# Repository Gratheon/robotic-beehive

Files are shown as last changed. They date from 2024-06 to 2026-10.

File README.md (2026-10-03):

### gratheon/robotic-beehive
[Gratheon Robotic beehive](https://gratheon.com/products/robotic_beehive/) is a project to build a robotic beehive that inspects the colony without harming it.

#### Robotic Beehive (concept v3)
A weatherproof cabinet around a standard vertical hive. To inspect a box, the robot:
1. peels the stack above it apart one edge at a time and lifts it 400 mm;
2. lifts each frame straight up until its comb centre is level with two cameras (one per face), photographs both faces straight on, then sets it down in the free gap beside it, like a beekeeper working through a box;
3. closes the hive with a rolling landing so bees are pushed aside, not crushed.

The stack can mix deep brood boxes and shallow honey supers.

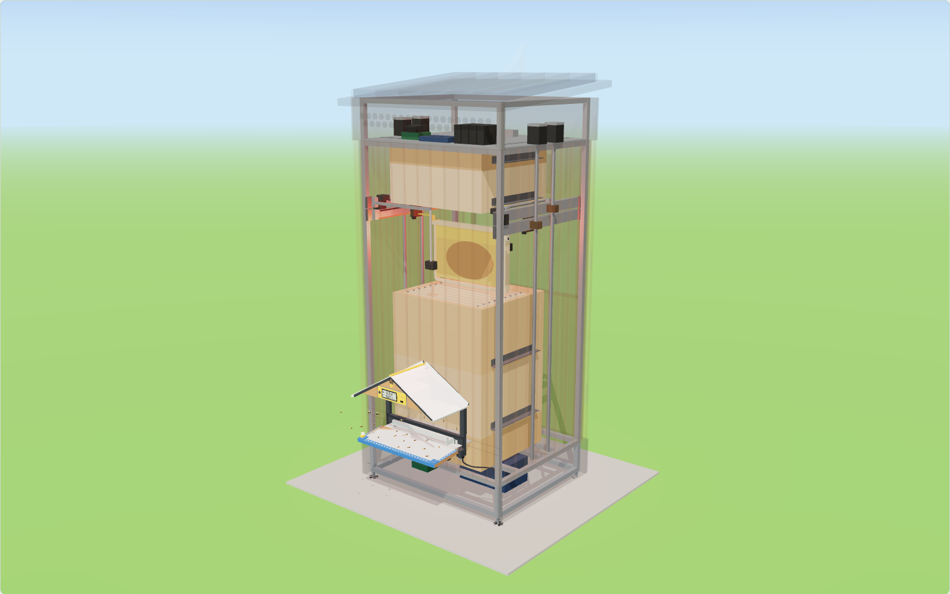
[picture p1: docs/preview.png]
Robotic Beehive 3D model: a frame lifted to the photo spot between the cameras (https://gratheon.com/products/robotic_beehive/)


**Live 3D preview:** [gratheon.com/products/robotic_beehive](https://gratheon.com/products/robotic_beehive/), or open `model/index.html` from this repo.

- **Design, bee welfare, weather, BOM, mobile roadmap:** [docs/DESIGN.md](docs/DESIGN.md)
- **Wiring:** [docs/WIRING.md](docs/WIRING.md)
- **3D model:** `model/index.html` (interactive, animated, opens from disk) and `model/hive-tower.glb` (the `inspection` animation clip is baked in)
- **Control code:** `hivebot/` (Python), plus a Klipper config in `firmware/klipper/hivebot.cfg`

#### View the model
Open `model/index.html` directly in a browser. It is a single self-contained file (three.js is bundled in) and works offline. Point at any part to see what it is and why it is there.

The model lives in `model/hive-model.js` (geometry and animation). The viewer is `viewer.js`, `viewer.html` and `viewer.css`. After a change, rebuild:
```bash
cd model && npm install   # first time only
npm run build             # regenerates index.html and hive-tower.glb
npm run website           # also updates the embed on gratheon.com (../../gratheon.com)
```

#### Run the controller
```bash
python3 -m pytest                    # sequences + bee-safety rules on the simulator
python3 -m hivebot plan --box 1      # dry run: every move, weights, visit time
python3 -m hivebot inspect --box 1   # real robot (Klipper + Moonraker on the Jetson)
python3 -m hivebot bench-move lift_left 700   # bench rig: DM542 on Jetson GPIO
```
The simulator refuses anything a careful beekeeper would refuse, such as landing the stack too fast or lifting a frame into bees hanging under the raised boxes. A code change that makes the robot rougher fails the tests.

#### Components
- NVIDIA Jetson Orin Nano: inspection, cameras, AI models, Klipper host
- BTT Octopus motion board running Klipper firmware
- 4 × NEMA23 on TR16×4 lead screws with DM542 drivers (2 lift beams, 2 scan beams)
- 2 × NEMA17 belt shuttles, 4 servos (forks, hooks)
- 2 × 12 MP frame cameras (one per face, straight on), 2 rim cameras, varroa sump camera
- ESP32 + LoRa always-on supervisor with load cells and climate sensors
- [Entrance Observer](https://github.com/Gratheon/entrance-observer) on the cabinet front (its own compute, PoE+ powered)
- 24 V power supply, optional solar + LiFePO4
- 22 mm aluminium extrusion skeleton

`main.py` is the original keyboard jog for a single DM542 on Jetson GPIO. The FreeCAD models of earlier concepts were removed in favour of `model/`; they remain in git history.

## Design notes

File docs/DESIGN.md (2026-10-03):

# Robotic Beehive: design (concept v3)

A static, weatherproof cabinet around a standard vertical hive. The robot inspects one box at a time:

1. It raises everything above that box by 400 mm, cracking the propolis seal one edge at a time.
2. It lifts each frame straight up, carries it to a photo spot in the middle of the box where two cameras, one per face, shoot both faces straight on, then sets it down in the free gap next to it.
3. It closes the hive again so that contact rolls across the rim.

Everything moving lives outside the bee space. The only changes to the hive itself are steel cleats on the boxes and two steel pins per frame.

- **3D model:** `model/index.html` (interactive, animated) and `model/hive-tower.glb` (with the `inspection` animation clip)
- **Wiring:** [WIRING.md](WIRING.md) and [wiring.svg](wiring.svg)
- **Control code:** `hivebot/` (Python) and `firmware/klipper/hivebot.cfg`

## 1. Why this layout

The hard problem is moving frames without killing bees. Frames are glued with propolis, the queen can be on any frame, and brood chills if it stays open too long. Three decisions follow from that:

| Decision | Why |
|---|---|
| **Lift frames straight up, never out sideways** | Bees that fall off a frame drop straight back into their own box, not onto the ground. The frame never tilts: warm, heavy comb breaks when it is not vertical. |
| **Split the stack instead of reaching in from the side** | Works with standard boxes. Side-opening boxes need custom joinery, and bees propolise every door shut. |
| **Put the hive in a cabinet** | Rain, wind and sun stay out. The air around an open box can be pre-warmed to 25 °C, so inspections are safe on 10–15 °C days. Disturbed bees stay inside instead of bothering neighbours, which matters for urban and corporate hives. The mechanics stay clean, and it can look like furniture instead of a pile of boxes. |

Two further choices do most of the bee-safety work:

- **Independent left/right lift beams.** Raising one edge 6 mm while the other stays down acts like a hive tool. It cracks the propolis seal with a fraction of the force a straight pull needs. Closing in the reverse order (left edge lands first, then right) makes the contact line roll across the rim and push bees aside.
- **The working gap.** Each box runs with one frame's worth of free space: 10 frames at 37.5 mm pitch leave a 25 mm gap. The robot works like a beekeeper:
  1. It pushes the frame next to the gap 10 mm into the gap, which breaks burr comb before lifting.
  2. It lifts the frame and photographs it.
  3. It sets the frame down in the gap. The gap has now moved one frame along.
  
  Lifting a frame straight up out of a full box would roll bees between the combs. That is how queens get killed.

## 2. Mechanism

Coordinates follow the model: X left/right, Y up, Z front (+, entrance) / back (−).

| Part | Specification |
|---|---|
| Skeleton | 4 corner posts of 22 mm aluminium extrusion, plinth ring, crown ring. Footprint 810 × 666 mm, height ≈1.88 m for two deep boxes and a super (≈1.99 m for three deep boxes; each extra box adds its own height). |
| Linear guides | MGN12 rail on the inner face of each post. Each post carries one lift-beam carriage and one scan-beam carriage. V-wheels on V-slot extrusion also work if the extrusion allows it. |
| Lift beams (L, R) | NEMA23 + DM542 + TR16×4 lead screw hung from the crown (the screw works in tension). A servo-turned fork shaft carries two fingers that swing under the box cleats. Bar load cells sit in the fork bearing blocks. |
| Scan beams (L, R) | Same drive as the lift beams. Each carries a belt-driven **shuttle** (NEMA17 + GT2) holding the frame hook and an inductive pin sensor. The scan beams lift each frame until its comb centre is level with the cameras. |
| Frame cameras | 2 × 12 MP (IMX477 class, 3.6 mm low-distortion M12 lens, about 83° × 67°), one per face, straight into the Orin Nano's two CSI ports. They hang from the **lift beams** (left beam: front camera, right beam: back camera), 265 mm in front of and behind the photo spot, between box and cladding, so they never pass over the hive. A ring strobe with crossed polarisers removes glare from nectar and capping. See *Cameras on the lift beams* and *Seeing into the cells* below. |
| Hook | A servo swings an L-shaped hook over the box wall. Its H-shaped tip plate has two back-to-back slots, so it can push a frame toward the gap in either direction. It slides sideways around the pin neck and never presses down on the top bars. Once the frame hangs, the pin head drops into a 1.5 mm pocket, so a lifted frame can be carried either way without sliding out. |
| Stack | Any mix of deep boxes (285 mm, 279 mm frames) for the brood nest and shallow supers (170 mm, 164 mm frames) for honey, set once per hive. The default is two deep boxes and one super. Cleats, pins and the 400 mm opening are the same for every box; the robot only needs each box's height. |
| Box changes | Stainless 30×30 angle cleat on the left and right walls of every box and the lid, 25 mm above the box bottom. They double as hand grips. |
| Frame changes | Two stainless M5 shoulder screws on each top bar ear (neck 2.5 mm, head 2.5 mm; they fit inside the bee space) and an ArUco tag on the end bar. |
| Bottom board | 150 mm tall screened "varroa sump": white tray, fixed wide-angle camera, no moving parts. |

**Cameras on the lift beams.** While a box is open the lift beams stand still at rim + 425 mm (cleat 25 mm + gap 400 mm), whatever the box. Cameras hung 265 mm below them therefore always sit 160 mm above the open rim, and the scan beam, now free of cameras, lifts each frame until its comb centre is level with them: 301.5 mm for a deep frame, 244 mm for a super frame. On the scan beam the cameras sat a fixed distance under the hook, which only centred one frame size.

The camera height has limits. For a deep frame it must be 150–165 mm above the rim, so the frame clears the rim and the scan beam stays 119 mm under the lift beam. So deep frames are centred with almost no room to move them up or down, while super frames have over 100 mm, enough to take two or three shots at different heights. A larger gap would give deep frames the same freedom, at the cost of a taller cabinet.

**Seeing into the cells.** A cell is 5.4 mm wide and about 11 mm deep, and it slopes up 9–13°. Eggs lie at the bottom, so to see an egg the camera must look within about 26° of the cell axis. Every frame is carried to the same photo spot, so distance, focus and mm-per-pixel are identical for every frame, and counts and cell sizes are comparable over time.

How many cameras is a cost/benefit question:

| Option | Cost | What it sees | Verdict |
|---|---|---|---|
| 1 camera, frame turned around | +1 camera, but a rotary axis on the hook carrying a 4 kg frame | Both faces, perfectly centred | Rotating a heavy, bee-covered frame inside the gap is a new failure mode (swinging comb, collisions). Not worth one camera. |
| **2 cameras, one per face (chosen)** | ≈€160, plug straight into the Orin Nano's two CSI ports | Whole face from 240 mm at about 9.5 px/mm (a cell ≈50 px, an egg ≈14 px). Centre of the comb within ~26°: eggs visible. Corners up to ~46°: larvae, capping, pollen and honey visible, eggs at the very bottom of a cell not. | Best balance. The brood nest, where eggs are, is usually the middle of the comb. |
| 4 cameras, two per face | ≈€320 plus a USB hub or CSI multiplexer | Worst corner ~35°, most of the comb within 25° | More cameras, cables and calibration for the comb corners, where eggs are rare. Only if the bench test shows corner eggs matter. |

Depth of field is not a reason for more cameras: comb is flat within about ±15 mm, and at 240 mm with the lens stopped to f/4–5.6 all of it is sharp.

Infrared is an open research question. The detection models Gratheon runs today (bees, queen, cells, varroa) are trained on visible-light photos, and cheap NoIR camera variants exist if a test shows infrared helps with mites or with seeing through the bees. Until then the cameras stay visible-light, with the white strobe.

**Bench test before buying hardware:** photograph a few real brood frames at 240 mm with one camera, centred and 45° off-axis, and count eggs found by eye and by the cell model. That decides between 2 and 4 cameras, and whether infrared is worth a second look.

- *Before (v3.0).* Cameras hung beside the frame's ends and looked along the face; the far half of the comb was seen up to 77° off-axis.
- *Low mount.* The cameras sit 10 mm below comb centre. Lower rows, whose cells slope away from the camera, are then seen more nearly along their axis.
- *Entrance.* The entrance is the [Entrance Observer](https://github.com/Gratheon/entrance-observer) porch, which runs through the cabinet front to the 300 mm slot. The scan beams never go below 535 mm, so the front camera always passes above it.
- *Short bee tunnel.* The hive stands 45 mm toward the cabinet front and the photo spot is 29 mm forward of the cabinet centre. The front camera still clears the hive by 10 mm, and the walk from the landing board to the hive entrance is about 70 mm instead of 115 mm.

**Why TR16×4 lead screws everywhere.** Each screw hangs from a thrust bearing in the crown, so the load puts it in tension and it cannot buckle.

- *Self-locking.* The lead angle is about 4.5°, so the stack or a frame stays put on power loss. No brakes needed.
- *Speed.* At 1.5 m length the whip limit is about 1000 rpm, which allows 40 mm/s frame lifts. The first choice, TR10×2, would have needed 1500 rpm, above its whip limit.
- *Torque.* Lifting 80 kg of honey supers needs ≈0.8 N·m per side, within a NEMA23's range at 24 V.

**Load limits.** The software stops a lift above 45 kg per side (90 kg of boxes above the target) and a peel above 60 kg. Heavy honey supers should be harvested before the stack outgrows that.

## 3. Inspection sequence

This is the sequence in `hivebot/sequences.py`. The simulator in `hivebot/motion/sim.py` enforces every rule in brackets.

1. **Pre-flight check** (`safety.evaluate`):
   - Outside ≥15 °C, or ≥10 °C with the cabinet pre-warmed to 25 °C.
   - No rain, wind below 8 m/s, between 10:00 and 16:00 (foragers are out).
   - At least 7 days since the last visit, battery OK, door closed, E-stop released.
2. Red work light on. Bees barely see light above ~620 nm.
3. The lift beams move to 8 mm below the cleats of the box above the target box. The forks swing in. *(A fork may only rotate at that height.)*
4. **Peel.** The left edge rises 6 mm at 1 mm/s, then the right edge. The load cells show the breakaway force and the weight of everything above, so the robot learns the weight of each box for free.
5. The stack rises 400 mm in 50 mm stages, checking the load after each stage. *(The stack may tilt at most 35 mm.)*
6. The scan beams rise to the rim. The pin sensors step across each expected pin position and re-locate every frame to ±1 mm.
7. **Each frame** (about 40 s):
   1. The hook lands 26 mm beside the pin at 8 mm/s. *(It may not land on a pin head.)*
   2. It slides onto the pin neck and pushes the frame 10 mm toward the gap.
   3. It peels the ears 2 mm, one end at a time, then lifts the frame at 40 mm/s until its comb centre is level with the cameras: 301.5 mm for a deep frame, 244 mm for a super. *(The frame top must stay 40 mm below the bees hanging under the raised stack.)*
   4. Carry the frame to the photo spot (middle of the box). Strobe and capture: 2 cameras, both faces straight on.
   5. The frame moves over the gap. It is lowered at 35 mm/s, and the last 20 mm at 3 mm/s. *(Checked.)*
   6. The hook slides off.
8. The scan beams park. The stack lowers to 30 mm above the rim.
9. **Rim check.** A camera counts bees on the contact edges. If it sees any, the robot waits 20 s, up to 3 times, then closes anyway: a slow rolling close beats a chilled box.
10. **Rolling close** in 2 mm steps at 2 mm/s. *(Landing faster is refused.)* If the load cells report contact more than 5 mm above the rim, the robot stops, backs off 20 mm and raises an alarm. That catches fingers, tools and fallen comb.
11. Forks out, beams park, photos upload.

**Timing (simulated):** ≈45 s per frame. A box is open for about 10 minutes. A full visit takes 9.5–12 minutes depending on which box. Run `python3 -m hivebot plan --box 1` to see every move with its duration. Only the target box is ever open; the rest of the stack stays closed and warm.

## 4. Bee welfare checklist

- No smoke. Bees stay calm in darkness and under red light.
- Short white strobe flashes, synced to the exposure, instead of constant bright light.
- Quiet motion: StealthChop on the shuttles, S-curve ramps, rubber pads between the hive and the plinth deck. Bees feel vibration in the wood far more than they hear airborne sound.
- Frames always vertical, gentle accelerations (≤80 mm/s²).
- Every slow zone is enforced in the simulator, so a code change that speeds up a landing fails the tests.
- Only one box open at a time, with open time budgeted and measured.
- Bees that drop fall back into their own box: frames and the stack are only ever directly above it.
- The cabinet keeps robbing bees, wasps and hornets away from the open box.
- The Entrance Observer porch keeps the flight path clear of every moving part. The service door is at the back, so the beekeeper never stands in the flight path.

## 5. Weather, materials, ecology

The Robotic Beehive follows the [hardware design principles](https://gratheon.com/docs/hardware-design-principles/) shared by all Gratheon hardware: wood first, aluminium where it must be strong, plastic only where nothing else works, A2 stainless fasteners, flat-pack parts from any workshop, every part replaceable, and bees first. Known deviation: the stainless box cleats and frame pins add metal to every box; hardwood cleats are worth testing.

| Area | Choice |
|---|---|
| Cladding | Vertical thermally-modified pine boards over a wood-fibre insulation board. No chemical wood preservatives, which harm bees. The plinth skirt is yakisugi (charred) wood against splash and rot. |
| Roof | Ventilated double roof, 60 mm overhang, drip edges, sloping down to the south. The 100 W solar panel sits on it. The air gap keeps summer heat off the hive. |
| Crown bay | Motors and electronics in a dry bay above the hive. Warm air leaves through the hex vent band (insect mesh behind). A Gore-type breather vent stops condensation. |
| Corrosion | Aluminium, stainless fasteners (nylon washers against aluminium), brass lead-screw nuts, dry PTFE lubrication. No grease, which collects debris and bees. |
| Hive humidity | Box seams stay closed except during a visit, so moist hive air does not reach the mechanics. The cabinet vents passively top and bottom. |
| Winter | The insulated cabinet cuts heat loss and wind chill, which improves overwintering. The robot does not inspect below 10 °C. It keeps logging weight and temperature. |
| End of life | Aluminium, steel, wood and one electronics bay, all separable with screws. No glued composites. |

## 6. Maintenance and human safety

- **Service door** (full height, at the back, away from the entrance). A wide window at frame height lets visitors watch an inspection, and an e-paper status display shows the last inspection, weight, temperature and next visit; the light bar under it is the robot state (pulsing yellow idle, solid yellow inspecting, red needs attention). A reed interlock cuts motor power when it opens. Fold the forks and the hive can be worked by hand like any other hive, using the cleats as handles.
- **E-stop** on a fixed stile at the back, next to the door handle, reachable without opening anything. It stays outside on purpose: opening the door already stops the motors through the interlock, so the button is for trouble while the door is closed. It cuts only the 24 V motor rail; the computers keep logging.
- **Watchdog.** The ESP32 supervisor holds relay K1 closed only while the Jetson sends heartbeats, so a hung computer means no motor power.
- **Nothing can drop.** The lead screws are self-locking, so power loss or an E-stop leaves the stack and frames where they are.
- **Pinch points.** Forks and hooks are painted yellow. Contact detection on closing stops on anything firmer than bees.
- **Modular.** Motors connect with GX16 plugs. Each beam unbolts from its carriages. The crown lid lifts off. All boards are standard and replaceable.
- **Service UI.** Klipper's web UI (Mainsail/Fluidd) jogs any axis for maintenance. `main.py` remains as the bench keyboard jog.

## 7. Compute, power, connectivity

| Unit | Role |
|---|---|
| Jetson Orin Nano | Inspection brain: runs `hivebot`, Klipper host and Moonraker, the cameras, and the detection models (bees, queen, brood, varroa). Powered only for inspections. |
| BTT Octopus + Klipper | Real-time step generation, homing, servos, heater and LED outputs. Python on Linux cannot time step pulses reliably, and the pulse jitter in `main.py` is that problem. |
| ESP32 + LoRa (e.g. Heltec V3) | Always-on supervisor at ~0.2 W. Handles weight, temperature, humidity, LoRa telemetry, waking the Jetson and the watchdog. |
| [Entrance Observer](https://github.com/Gratheon/entrance-observer) | Mounted on the cabinet front in its robot configuration. Its own pod (Raspberry Pi 5 + Hailo-8) counts bees in and out, flags hornets and robbing, and runs the entrance gate. Powered over PoE+ from a 24 V injector in the plinth. |

**Energy per day:**

| Load | Energy |
|---|---|
| Supervisor | ≈5 Wh |
| Weekly inspection (Jetson 15 W for 15 min, motors ≈50 W average for 12 min) | ≈15 Wh, plus up to 20 Wh of heater on cool days |
| Entrance Observer (its own estimate) | ≈27 Wh sampled (2 min every 10 min), ≈111 Wh continuous in flight weather: the largest consumer |

A 100 W panel gives roughly 300–400 Wh/day in an Estonian summer and far less in winter. So off-grid, the Entrance Observer runs in the season and sleeps in winter.

**Antennas.** All antennas sit in one RF-transparent fin on the roof ridge, above everything metal:

- LTE MIMO and GNSS go to a USB modem.
- LoRa 868 MHz goes to the ESP32.
- Wi-Fi goes to the Orin's M.2 card.

Coax runs are short (crown to roof, under 0.5 m) with surge arrestors where they enter. The frame is bonded to an earth rod.

## 8. From static tower to mobile robot

The skeleton is designed as a separable **yoke**: posts, beams and crown are one unit. The hive side is a **dock**: plinth, bottom board, cleated boxes. Two steps later:

1. **Shared yoke on a trolley.** The yoke unbolts from one dock and bolts onto the next. Three docking cones in V-grooves set it back within ±0.5 mm, so frame positions and cleat heights stay valid.
2. **Wheeled yoke (robotic apiary).** The same yoke on a skid-steer base, open at the back. It drives over a dock from behind, away from the flight path, lowers onto the cones and runs the same `hivebot` sequence. Each dock then needs only a light weather hood with a rear door. The expensive part (yoke, motors, compute) is shared across about 10 hives.

This is why the model keeps all motors and electronics on the yoke, and why frame positions are stored per hive and re-checked by the pin sensors on every visit.

## 9. Bill of materials (new parts, EUR, rough 2026 prices)

Parts you already have (Jetsons, 24 V PSU, extrusions, NEMA23s, DM542s) are counted at €0 where noted.

| Group | Items | € |
|---|---|---|
| Motion | MGN12 rails ×4 with carriages 120 · TR16×4 screws ×4 with brass nuts 90 · BK/BF12 bearing sets ×4 60 · couplings 20 · NEMA17 ×2 + GT2 belts and pulleys 40 · servos ×4 (waterproof metal gear) 60 · fork shafts, bearings, 2 load cells + HX711 35 · extra NEMA23/DM542 if short 0–130 · brackets, T-nuts, stainless fasteners 40 | 465–595 |
| Hive kit | Stainless cleats for 4 boxes + lid 30 · frame pins (80) 20 · ArUco tags 5 | 55 |
| Electronics | BTT Octopus 70 · NVMe 256 GB 30 · 12 MP cameras ×2 (IMX477 class + 3.6 mm M12 lens, direct CSI) 160 · polariser film 15 · varroa camera 25 · LED ring strobes + red strip 30 · ESP32 LoRa 25 · LTE modem 45 · antennas, bulkheads, surge arrestors 50 · DC-DC ×3 35 · E-stop, reed switch, relays, fuses, GX16, glands 60 · endstops + inductive sensors 20 · climate sensors 15 · cable chains and cable 40 · PTC heater 20 · sealed PSU box 20 | 700 |
| Cabinet | Thermo-pine cladding ~6 m² 120 · wood-fibre board 40 · plywood backers, roof board 60 · charred skirt 25 · polycarbonate window 15 · hinges, lock, EPDM seals, insect mesh, hex vent panel 60 · levelling feet 20 · roof flashing 20 | 360 |
| **Total** | | **≈1,580–1,710** |
| Solar option | 100 W panel 70 · 24 V MPPT 50 · LiFePO4 24 V 20 Ah 200 | 320 |

Ways to cut cost:
- V-wheels instead of rails (−€90).
- Painted plywood instead of thermo-pine (−€60).
- Skip the heater and inspect only on warm days (−€20).

## 10. Risks and open questions to test first

1. **Propolis breakaway force** between boxes after a full season. Measure it with a luggage scale on real hives. The 60 kg peel limit is a guess.
2. **Burr comb between boxes.** Bees build comb across the seam, and lifting tears it. The rim camera should detect it; the robot may need a heated wire or a thin blade swept along the seam before the peel.
3. **Pin fit.** A 6 mm slot on a 5 mm neck needs frames positioned to ±1 mm. The sensor search gives that, but swollen or warped frames need testing.
4. **Bees festooning under the raised stack.** The 40 mm clearance above a lifted frame should be checked against real clusters.
5. **Condensation** in the cabinet in autumn. Log humidity in the crown and near the rails.
6. **Mice and wax moths** in the plinth and cabinet. Use mesh on every vent and the Entrance Observer gate as a mouse guard.

## 11. More ideas for bees and beekeepers

- **Per-box weight for free.** Lifting at different seams tells the robot how heavy each box is. It can report honey flow and time the harvest.
- **Frame identity over time.** ArUco tags plus the Gratheon web app's frame-side history give a time-lapse of each comb face: brood pattern, queen laying rate, honey arc.
- **Queen-safe mode.** If the detector sees the queen on a frame, set that frame down slower and skip the nudge.
- **Motorised entrance reducer** (already in the model): closes against robbing or hornets, narrows in wind and winter, closes for transport.
- **Varroa sump camera:** a daily mite-drop count with no drawer to pull. Combined with frame photos it gives a treatment trigger.
- **Heating and ventilation hooks.** The cabinet heater and crown fan are already on the motion board, ready for the Hive heating and Ventilation control ideas.
- **Visitor window with shutter** in the back door for school groups and corporate sponsorship programmes, closed by default so the hive stays dark.
- **Feeder port** through the lid for a syrup line, filled from outside the cabinet.

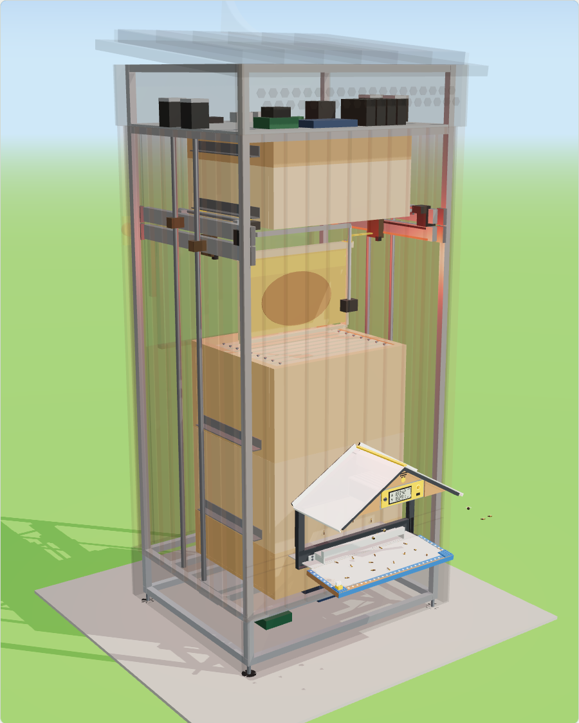
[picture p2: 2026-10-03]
docs/hero.png

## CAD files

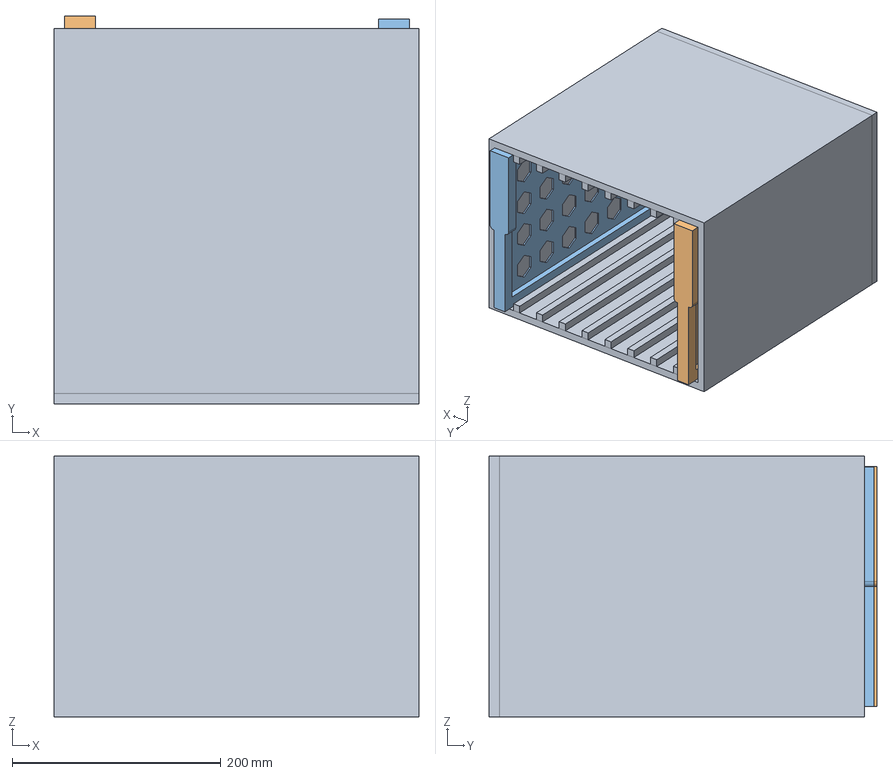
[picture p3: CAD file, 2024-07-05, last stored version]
CAD-model/beehive-box/beehibe-box-closed-asm.FCStd
350.0 x 371.8 x 250.0 mm
hive-box_001
hube-frame_001
hube-frame_002

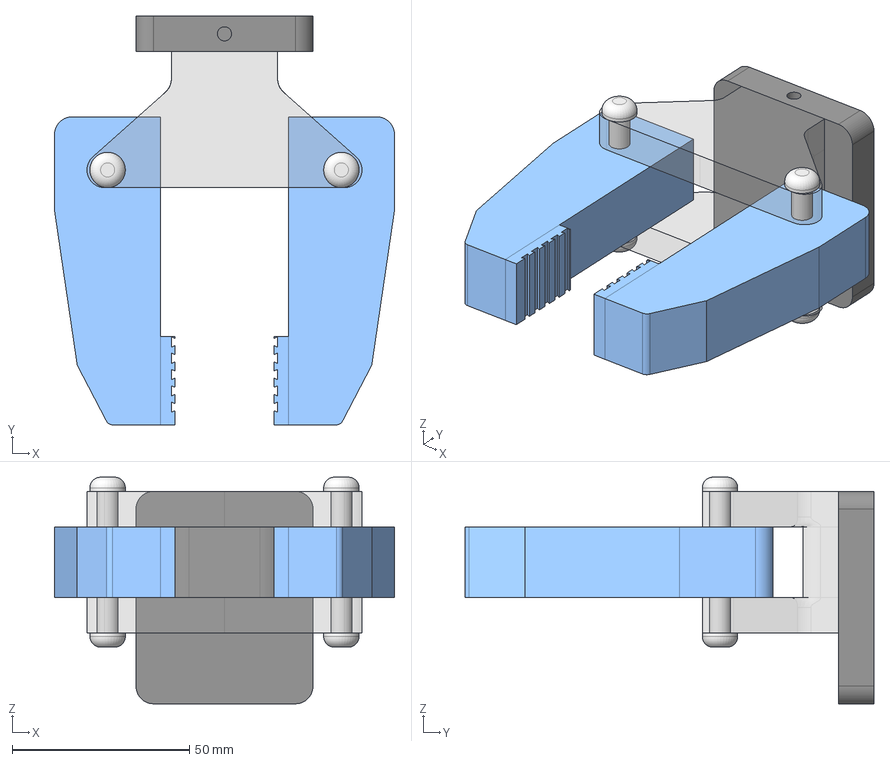
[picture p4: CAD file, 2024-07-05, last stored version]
CAD-model/gripper/GripperStatic-asm.FCStd
96.0 x 115.4 x 64.0 mm
GripperFrame_001
GripperPin_001
GripperPin_002
GripperPlate_001
GripperJaws_001
GripperJaws_002

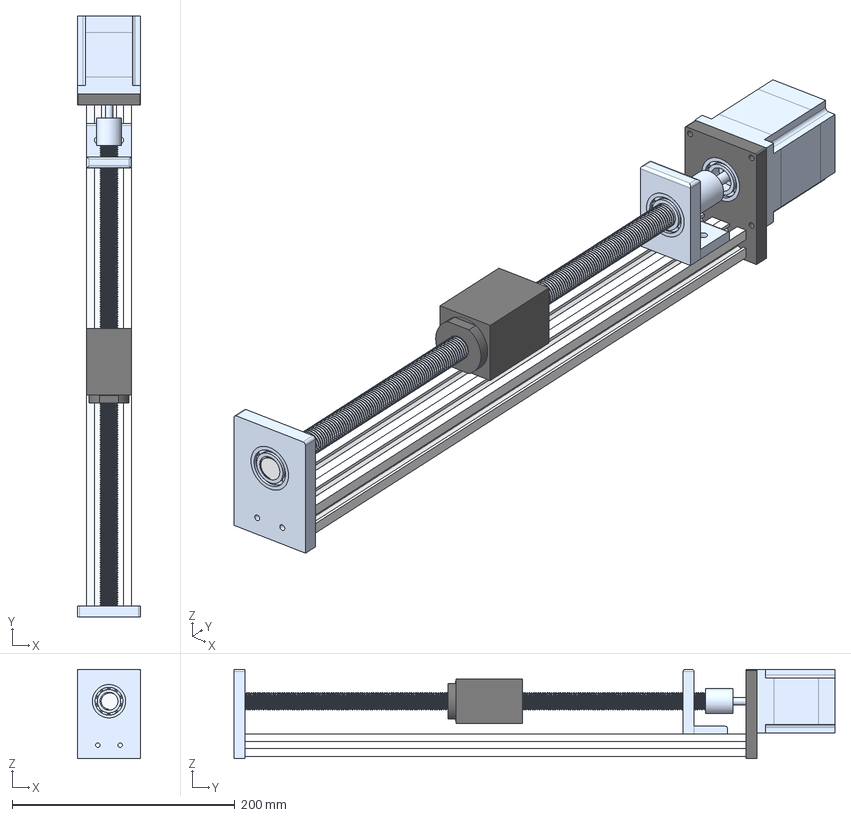
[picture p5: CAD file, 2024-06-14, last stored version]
Assembly.FCStd
57.0 x 540.0 x 80.0 mm
Plate-Holder-Incomplete_001
Aluminium Extrusion_001
Aluminium Extrusion_002
endBearingPlate_002
30mm bearing_001
30mm bearing_002
nema23-updated_001
xouple-bush_001
middleBearingBracket_001
30mm bearing_003
final-lead-screw_001
ballscrew_001

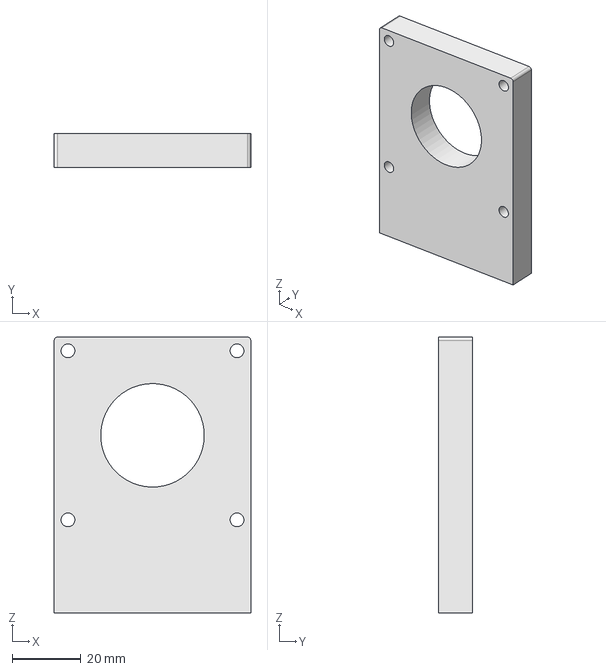
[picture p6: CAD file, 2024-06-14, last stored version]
Plate-Holder-Incomplete.FCStd
57.0 x 10.0 x 80.0 mm

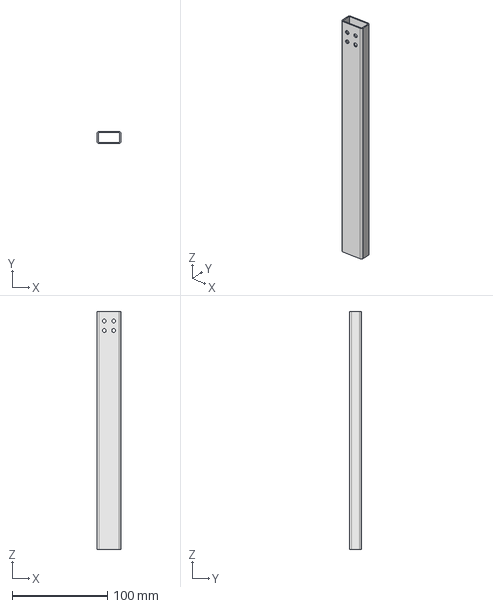
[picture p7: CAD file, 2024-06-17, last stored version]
CAD-model/aluminium-extrusion/Aluminium-Bar.FCStd
25.0 x 12.5 x 250.0 mm

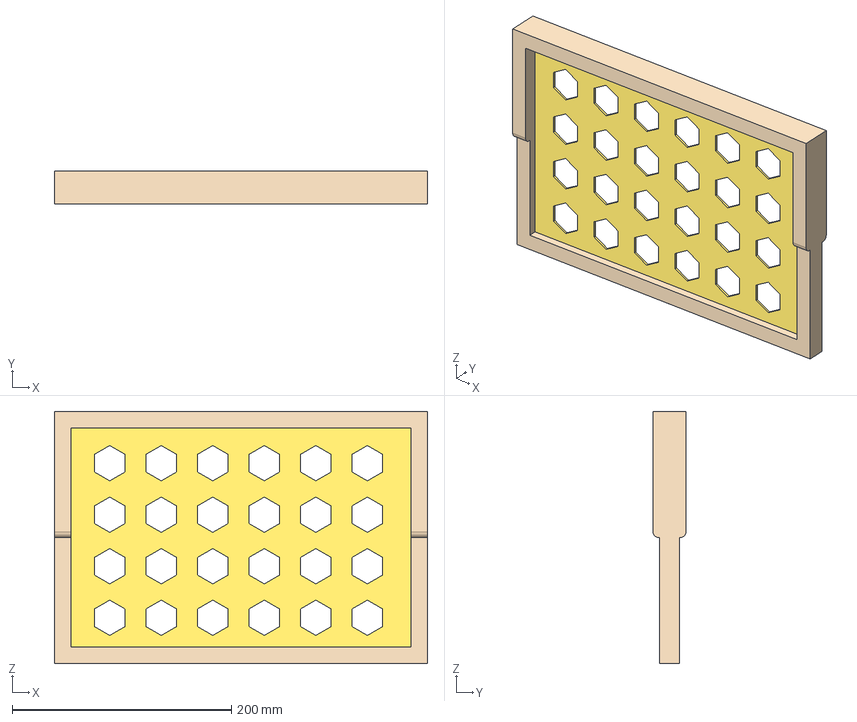
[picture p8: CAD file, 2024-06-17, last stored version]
CAD-model/beehive-frame/hube-frame.FCStd
340.0 x 30.0 x 230.0 mm

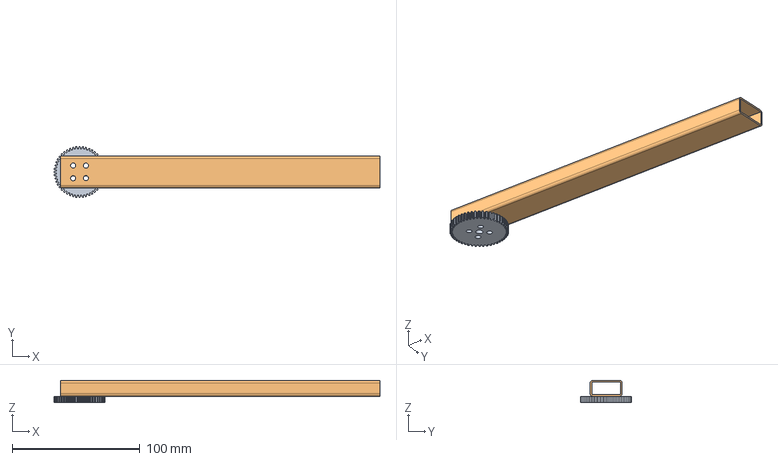
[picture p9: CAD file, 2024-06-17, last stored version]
CAD-model/cameras-butterfly-mechanism/butterfly-mechanism-static.FCStd
255.0 x 40.0 x 17.5 mm
48T0.8M-Gear_001
Aluminium-Bar_001

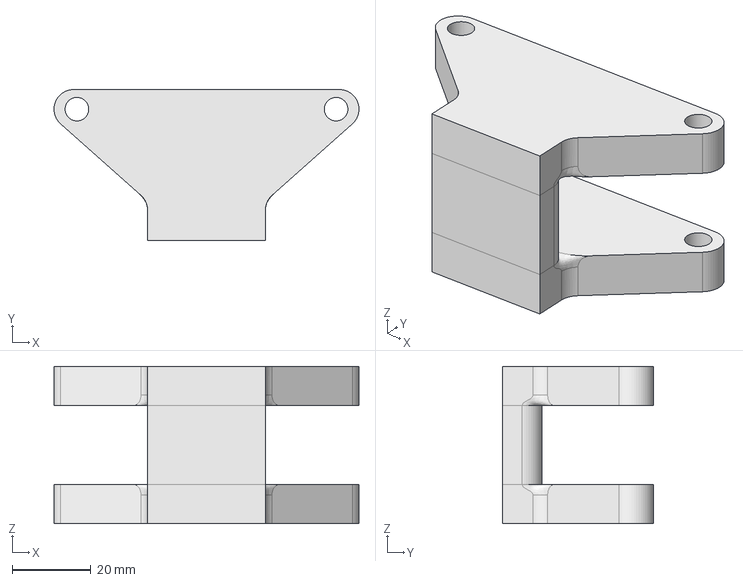
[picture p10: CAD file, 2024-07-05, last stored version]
CAD-model/gripper/GripperFrame.FCStd
77.7 x 38.4 x 40.0 mm

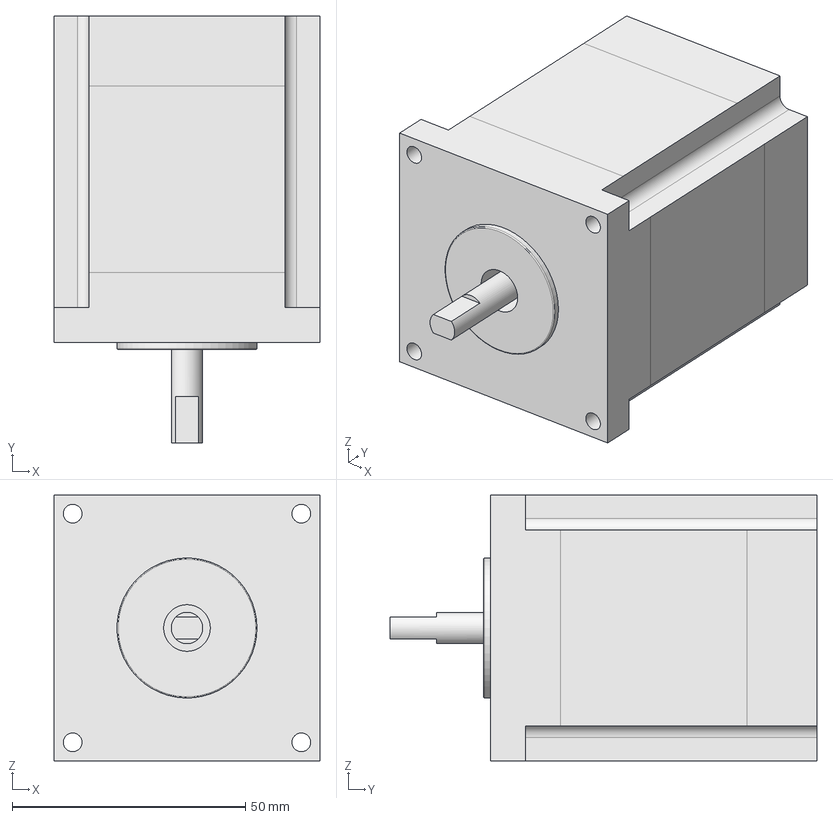
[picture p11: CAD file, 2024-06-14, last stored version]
CAD-model/stepper-motor-nema/nema23-updated.FCStd
57.0 x 91.5 x 57.0 mm

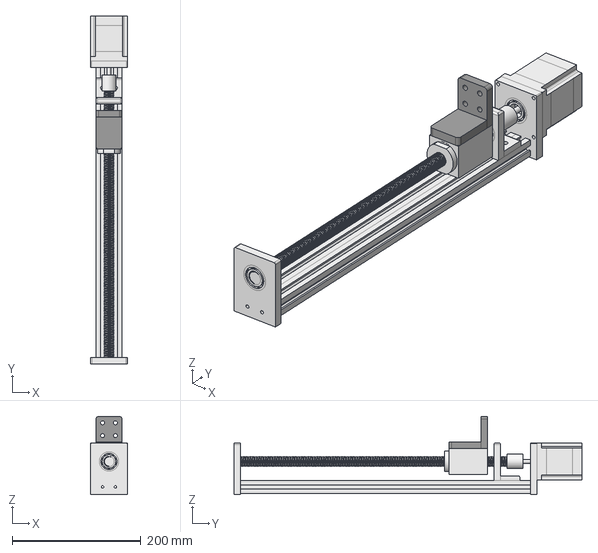
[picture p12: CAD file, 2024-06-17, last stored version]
GuideWithClampInitialStage.FCStd
57.0 x 540.0 x 121.5 mm
Guide-Static-Initial_001
40x60x50-Plate_001

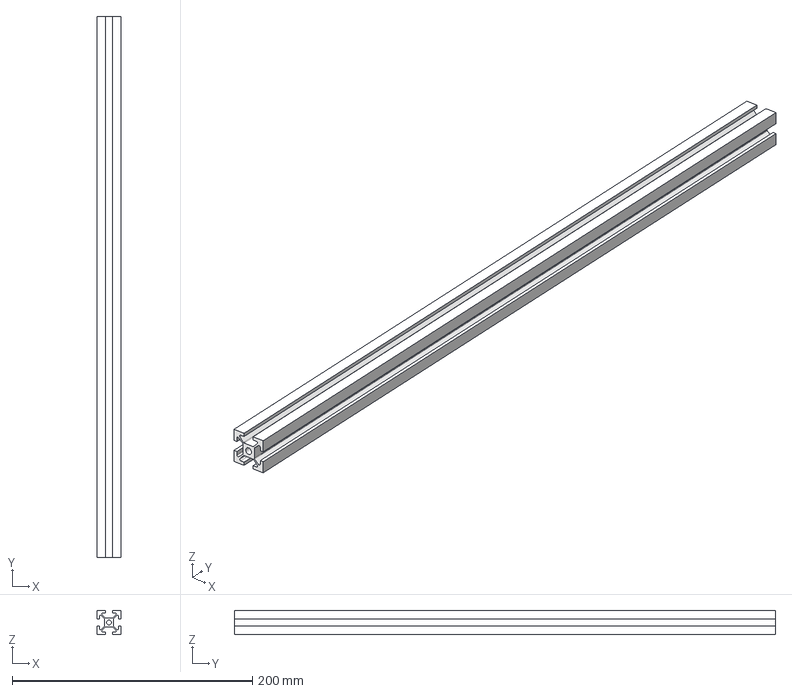
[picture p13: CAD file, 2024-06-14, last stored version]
CAD-model/aluminium-extrusion/Aluminium Extrusion.FCStd
20.0 x 450.0 x 20.0 mm

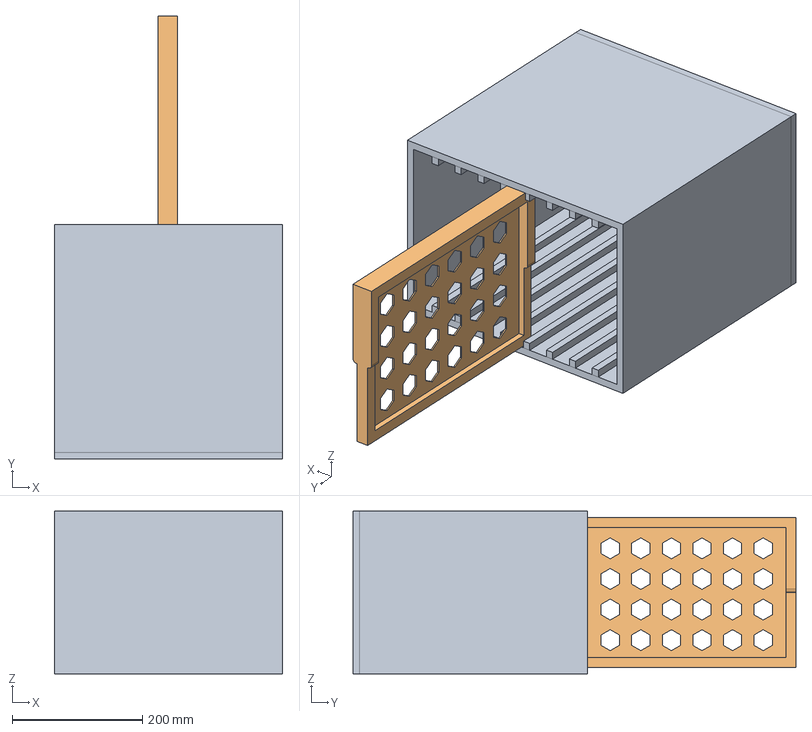
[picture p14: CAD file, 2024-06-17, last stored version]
CAD-model/beehive-box/beehivebox-static.FCStd
350.0 x 680.0 x 250.0 mm
hive-box_001
hube-frame_001

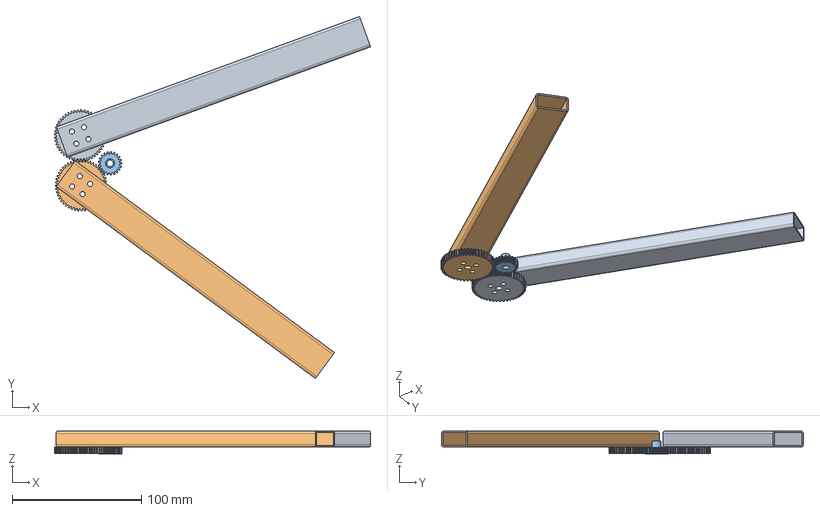
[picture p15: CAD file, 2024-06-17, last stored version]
CAD-model/cameras-butterfly-mechanism/Butterfly-Static.FCStd
245.1 x 280.5 x 17.7 mm
butterfly-mechanism-static_001
butterfly-mechanism-static_002
48T0.8M-Pinion_001

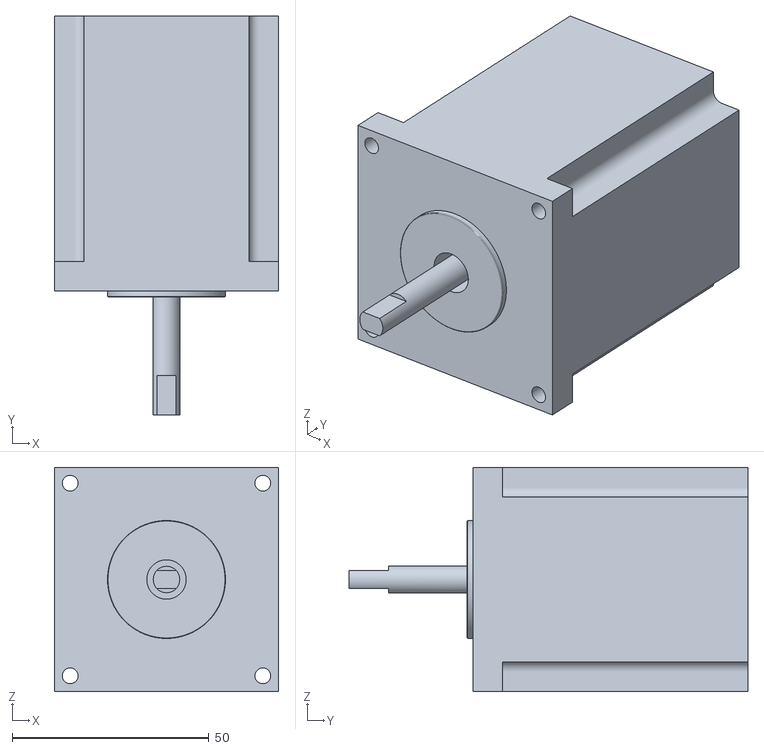
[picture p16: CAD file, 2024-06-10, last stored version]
CAD-model/stepper-motor-nema/StepperExportStl.stl
57.0 x 101.5 x 57.0

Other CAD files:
CAD-model/Full-Assembly-Animation.FCStd
CAD-model/gantry/Gantry.FCStd
TlatPlate-temporary.FCStd
30mm bearing.FCStd
40x60x50-Plate.FCStd
CAD-model/gripper/GripperPin.FCStd
CAD-model/gripper/GripperPlate.FCStd
CAD-model/gripper/grip.FCStd
CAD-model/linear-screw-guide/30mm bearing.FCStd
CAD-model/linear-screw-guide/40x60x50-Plate.FCStd
CAD-model/linear-screw-guide/CADLatest.FCStd
CAD-model/linear-screw-guide/Guide-WO-ballscrew.FCStd
CAD-model/linear-screw-guide/LienarGuide-low-BallScrew.FCStd
CAD-model/linear-screw-guide/LinearGuide-Clamp.FCStd
CAD-model/linear-screw-guide/TlatPlate-temporary.FCStd
CAD-model/linear-screw-guide/ball bearing.FCStd
CAD-model/linear-screw-guide/ballscrew.FCStd
CAD-model/linear-screw-guide/endBearingPlate.FCStd
CAD-model/linear-screw-guide/middleBearingBracket.FCStd
CAD-model/linear-screw-guide/plateHolder.FCStd
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

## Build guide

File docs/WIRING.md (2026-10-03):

# Robotic Beehive wiring

Electrical block diagram

Regenerate the diagram with `python3 docs/wiring_diagram.py`.

## Power

| Rail | Source | Protection | Loads | Wire |
|---|---|---|---|---|
| 24 V bus | PSU ~350 W (or LiFePO4 via ideal diode) | main fuse 15 A | everything below | 2.5 mm² |
| Logic (F1) | 24 V bus | 5 A | Octopus logic input, ESP32 (onboard buck), DC-DC 24→19 V (Orin Nano), DC-DC 24→5 V (USB hub), PoE+ injector 24→48 V 30 W (Entrance Observer) | 1.0 mm² |
| Motor rail (F2) | 24 V bus → E-stop (NC) → door reed (NC) → relay K1 | 10 A | 4 × DM542, Octopus motor input (TMC2209 shuttles), DC-DC 24→6 V 10 A (servos) | 1.5 mm² |
| Heater (F3) | 24 V bus via Octopus HE0 MOSFET (PA2) | 5 A | 24 V PTC fan heater ≤100 W | 1.0 mm² |
| LEDs, fans (F4) | 24 V bus via Octopus FAN0/1/2 MOSFETs | 3 A | strobe bars, 660 nm red strip, crown fan | 0.5 mm² |

K1 is held closed by the ESP32 watchdog only while the Jetson sends heartbeats. The E-stop and the door reed are in series in the coil circuit and in the rail, so either one alone removes motor power. The lead screws are self-locking, so nothing drops when that happens.

## Motors

| Axis | Motor | Driver | Board slot | Cable |
|---|---|---|---|---|
| lift_left | NEMA23 | DM542 (1600 p/rev) | MOTOR0 via external-driver adapter | 4×0.75 mm² shielded, GX16-4, shield to driver GND |
| lift_right | NEMA23 | DM542 | MOTOR1 | as above |
| scan_left | NEMA23 | DM542 | MOTOR2 | as above |
| scan_right | NEMA23 | DM542 | MOTOR3 | as above |
| shuttle_left | NEMA17 | TMC2209 (UART PF2) | MOTOR4 | 4×0.25 mm² in the cable chain |
| shuttle_right | NEMA17 | TMC2209 (UART PE4) | MOTOR5 | as above |

**DM542 signals.** DM542 inputs are opto-isolated and want about 5 V. Take STEP/DIR/EN from the MOTOR0–3 sockets through a buffered 3.3 V→5 V external-driver adapter (74HCT245 or BTT's adapter). Wire PUL−/DIR−/ENA− to GND and PUL+/DIR+/ENA+ to the buffered signals.

**DM542 settings.** Set the current to the motor's rated current and turn half-current at standstill on. Keep the drivers in the crown next to the board so step lines stay short. The motors are in the crown too.

## Inputs (all to the Octopus, see `firmware/klipper/hivebot.cfg`)

| Signal | Pin | Device |
|---|---|---|
| Endstop lift L / R | PG6 / PG9 | micro-switch, NC, at the bottom of travel |
| Endstop scan L / R | PG10 / PG11 | micro-switch, NC |
| Endstop shuttle L / R | PG12 / PG13 | micro-switch, NC, back end |
| Frame pin sensor L / R | PG14 / PG15 | inductive M8 NPN; powered from 24 V, signal through a 10k/4.7k divider or an optocoupler |
| Door closed | PE14 | reed switch (second contact; the first is in the motor rail) |
| E-stop released | PE15 | auxiliary NC contact of the E-stop |
| Cabinet temperature | PF4 | 100k NTC (3950) |

## Outputs

| Signal | Pin | Device |
|---|---|---|
| Servo fork L / R | PB6 / PB7 | DS3218-class waterproof servo, power from the 6 V bus |
| Servo hook L / R | PE12 / PE13 | as above |
| Strobe | PA8 (FAN0) | 24 V white LED rings on the 2 frame cameras |
| Red work light | PE5 (FAN1) | 24 V 660 nm LED strip on both scan beams |
| Crown fan | PD12 (FAN2) | 24 V 60 mm fan |
| Cabinet heater | PA2 (HE0) | 24 V PTC fan heater |

Pin names follow BTT's Octopus v1.1 / Pro pinout. Check them against your board revision before connecting motors.

## Supervisor (ESP32 + LoRa)

| Function | Connection |
|---|---|
| Load cells (fork blocks) | 2 × HX711, one per side |
| Climate | BME280 inside the cabinet, BME280 outside (shaded), DS18B20 in each hive box |
| Jetson power | relay or MOSFET on the 19 V feed; wakes the Orin for inspections |
| Motor watchdog | drives relay K1 |
| Jetson link | UART to the Orin 40-pin header (pins 8/10), 3.3 V |
| Radio | LoRa 868 MHz from the antenna fin |

## Grounding and cabling

- Bond the aluminium skeleton, crown plate, PSU earth and antenna surge arrestors to PE and to an earth rod at the cabinet.
- Ground motor cable shields at the driver end only.
- Moving beams get their cables through vertical cable chains on the back posts. Use high-flex cable and strain relief at both ends.
- Every cable entering the crown goes through a gland. Every connector below the crown is IP67 (GX16 with boots, or M12).

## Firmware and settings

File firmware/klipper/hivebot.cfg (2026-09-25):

# Klipper configuration for the Robotic Beehive.
#
# Board: BTT Octopus v1.1 / Octopus Pro (STM32). Pin names follow BTT's
# published pinout; check them against your board revision before powering
# motors. Host: Klipper + Moonraker on the Jetson Orin Nano.
#
# Axes are manual_steppers in millimetres of absolute height (see
# hivebot/config.py). The Python orchestrator (hivebot) sends moves; this file
# only describes hardware.
#
#   MOTOR0  lift_left      NEMA23  external DM542   TR16x4
#   MOTOR1  lift_right     NEMA23  external DM542   TR16x4
#   MOTOR2  scan_left      NEMA23  external DM542   TR16x4
#   MOTOR3  scan_right     NEMA23  external DM542   TR16x4
#   MOTOR4  shuttle_left   NEMA17  TMC2209          GT2 20T
#   MOTOR5  shuttle_right  NEMA17  TMC2209          GT2 20T
#
# DM542 wiring: take STEP/DIR/EN from the MOTOR0-3 driver sockets through an
# "external driver adapter" (3.3 V -> 5 V buffered). PUL-/DIR-/ENA- to GND,
# PUL+/DIR+/ENA+ to the buffered signals. DIP switches: 1600 pulses/rev
# (8 microsteps), current = motor rated current, half-current at standstill ON.

[mcu]
serial: /dev/serial/by-id/usb-Klipper_stm32f446xx_CHANGE_ME-if00

[printer]
kinematics: none
max_velocity: 80
max_accel: 400

# --- vertical axes (DM542) --------------------------------------------------
[manual_stepper lift_left]
step_pin: PF13
dir_pin: PF12
enable_pin: !PF14
microsteps: 8
full_steps_per_rotation: 200
rotation_distance: 4
step_pulse_duration: 0.000005
velocity: 15
accel: 40
endstop_pin: ^PG6

[manual_stepper lift_right]
step_pin: PG0
dir_pin: !PG1
enable_pin: !PF15
microsteps: 8
full_steps_per_rotation: 200
rotation_distance: 4
step_pulse_duration: 0.000005
velocity: 15
accel: 40
endstop_pin: ^PG9

[manual_stepper scan_left]
step_pin: PF11
dir_pin: PG3
enable_pin: !PG5
microsteps: 8
full_steps_per_rotation: 200
rotation_distance: 4
step_pulse_duration: 0.000005
velocity: 40
accel: 80
endstop_pin: ^PG10

[manual_stepper scan_right]
step_pin: PG4
dir_pin: !PC1
enable_pin: !PA0
microsteps: 8
full_steps_per_rotation: 200
rotation_distance: 4
step_pulse_duration: 0.000005
velocity: 40
accel: 80
endstop_pin: ^PG11

# --- shuttles (TMC2209 on the board) ----------------------------------------
[manual_stepper shuttle_left]
step_pin: PF9
dir_pin: PF10
enable_pin: !PG2
microsteps: 16
rotation_distance: 40
velocity: 80
accel: 400
endstop_pin: ^PG12

[tmc2209 manual_stepper shuttle_left]
uart_pin: PF2
run_current: 0.8
stealthchop_threshold: 999999   # StealthChop always: quiet for the bees

[manual_stepper shuttle_right]
step_pin: PC13
dir_pin: !PF0
enable_pin: !PF1
microsteps: 16
rotation_distance: 40
velocity: 80
accel: 400
endstop_pin: ^PG13

[tmc2209 manual_stepper shuttle_right]
uart_pin: PE4
run_current: 0.8
stealthchop_threshold: 999999

# --- servos -----------------------------------------------------------------
# Waterproof metal-gear servos (DS3218 class), powered from the 6 V buck, not
# from the board. Only the signal wire goes to these pins.
[servo fork_left]
pin: PB6
maximum_servo_angle: 180
minimum_pulse_width: 0.0005
maximum_pulse_width: 0.0025
initial_angle: 0

[servo fork_right]
pin: PB7
maximum_servo_angle: 180
minimum_pulse_width: 0.0005
maximum_pulse_width: 0.0025
initial_angle: 0

[servo hook_left]
pin: PE12
maximum_servo_angle: 180
minimum_pulse_width: 0.0005
maximum_pulse_width: 0.0025
initial_angle: 0

[servo hook_right]
pin: PE13
maximum_servo_angle: 180
minimum_pulse_width: 0.0005
maximum_pulse_width: 0.0025
initial_angle: 0

# --- inputs -------------------------------------------------------------------
# Inputs are polled by hivebot via Moonraker (gcode_button state).
[gcode_macro _NOOP]
gcode:
  G4 P0

# Inductive M8 sensors (NPN, 3 mm range) that find the steel frame pins.
# Feed them from 24 V; the signal goes through the endstop port's pull-up and
# a 10k/4.7k divider or an optocoupler.
[gcode_button pin_left]
pin: ^!PG14
press_gcode: _NOOP
release_gcode: _NOOP

[gcode_button pin_right]
pin: ^!PG15
press_gcode: _NOOP
release_gcode: _NOOP

# Door and E-stop are wired normally-closed, so a broken wire reads as unsafe.
# Both also cut the 24 V motor rail in hardware; these inputs are for logging
# and for refusing to start.
[gcode_button door_closed]
pin: ^!PE14
press_gcode: _NOOP
release_gcode: _NOOP
  M112

[gcode_button estop_ok]
pin: ^!PE15
press_gcode: _NOOP
release_gcode: _NOOP
  M112

# --- outputs ------------------------------------------------------------------
[output_pin strobe]        # 24 V white LED bars on the cameras (FAN0 MOSFET)
pin: PA8
value: 0

[output_pin red_light]     # 24 V deep-red (660 nm) work light (FAN1 MOSFET)
pin: PE5
pwm: True
value: 0

[fan_generic crown_fan]    # crown bay exhaust (FAN2)
pin: PD12

# --- cabinet heater ------------------------------------------------------------
# 24 V PTC fan heater on HE0, NTC 100k in the cabinet air near the hive.
[heater_generic cabinet]
heater_pin: PA2
sensor_type: Generic 3950
sensor_pin: PF4
control: watermark
max_delta: 1.0
min_temp: -30
max_temp: 45

[verify_heater cabinet]
max_error: 120
check_gain_time: 900
hysteresis: 5
heating_gain: 1

[temperature_sensor crown]
sensor_type: temperature_host   # Jetson SoC temperature

[idle_timeout]
timeout: 600
gcode:
  M84   # screws are self-locking: dropping power holds position

[force_move]
enable_force_move: True   # service jogging from the Mainsail/Fluidd UI

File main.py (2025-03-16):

from time import sleep
import Jetson.GPIO as GPIO
import threading
import sys
import readchar
import select
import termios
import tty

PUL = 33  # Stepper Drive Pulses
DIR = 40  # Controller Direction Bit (High for Controller default / LOW to Force a Direction Change).
ENA = 22  # Controller Enable Bit (High to Enable / LOW to Disable).

# GPIO.setmode(GPIO.BCM)
GPIO.setmode(GPIO.BOARD) # Jetson Nano

GPIO.setup(PUL, GPIO.OUT)
GPIO.setup(DIR, GPIO.OUT)
GPIO.setup(ENA, GPIO.OUT)

print('Initialization Completed')

# Motor control parameters
delay = 0.00005  # Delay between PUL pulses - effectively sets the motor rotation speed
print('Speed set to ' + str(delay))

# Control flags
running = True
motor_running = False
direction_forward = True

def pulse_motor():
    """Function to continuously pulse the motor while motor_running is True"""
    global motor_running, direction_forward

    while running:
        if motor_running:
            # Set direction
            if direction_forward:
                GPIO.output(DIR, GPIO.LOW)
                print('Moving Forward')
            else:
                GPIO.output(DIR, GPIO.HIGH)
                print('Moving Backward')

            # Enable motor
            GPIO.output(ENA, GPIO.HIGH)

            # Pulse the motor as long as motor_running is True
            while motor_running and running:
                GPIO.output(PUL, GPIO.HIGH)
                sleep(delay)
                GPIO.output(PUL, GPIO.LOW)
                sleep(delay)

            # Disable motor when stopped
            GPIO.output(ENA, GPIO.LOW)

        sleep(0.01)  # Small delay to prevent CPU hogging

def keyboard_listener():
    """Listen for keyboard input"""
    global motor_running, direction_forward, running

    print("Keyboard controls:")
    print("- Press UP arrow key (↑) to move forward")
    print("- Press DOWN arrow key (↓) to move backward")
    print("- Press SPACE to stop the motor")
    print("- Press ESC or Q to exit")

    # Set up non-blocking keyboard input
    old_settings = termios.tcgetattr(sys.stdin)
    try:
        tty.setcbreak(sys.stdin.fileno())

        while running:
            # Check if there's input available
            if select.select([sys.stdin], [], [], 0.1)[0]:
                key = readchar.readkey()

                if key == readchar.key.UP:
                    direction_forward = True
                    motor_running = True
                    print("Up key pressed - Moving forward")
                elif key == readchar.key.DOWN:
                    direction_forward = False
                    motor_running = True
                    print("Down key pressed - Moving backward")
                elif key in (readchar.key.ESC, 'q', 'Q'):
                    print("Exiting program")
                    stop_program()
                    break
                elif key == readchar.key.SPACE:
                    motor_running = False
                    print("Space pressed - Stopping motor")
            else:
                # No key is being pressed, stop the motor
                if motor_running:
                    motor_running = False
                    print("No key pressed - Stopping motor")
    finally:
        # Restore terminal settings
        termios.tcsetattr(sys.stdin, termios.TCSADRAIN, old_settings)

def stop_program():
    """Clean up and exit the program"""
    global running
    running = False
    motor_running = False
    print("Cleaning up GPIO")
    GPIO.cleanup()
    print("Exiting program")

# Start the motor control thread
motor_thread = threading.Thread(target=pulse_motor)
motor_thread.daemon = True
motor_thread.start()

# Start keyboard listener thread
try:
    keyboard_thread = threading.Thread(target=keyboard_listener)
    keyboard_thread.daemon = True
    keyboard_thread.start()

    # Keep the main thread alive until keyboard_thread exits
    keyboard_thread.join()
except KeyboardInterrupt:
    stop_program()
finally:
    stop_program()

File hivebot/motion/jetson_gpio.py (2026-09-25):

"""Bench backend: step/dir straight from the Jetson 40-pin header to DM542s.

This is the setup main.py already uses (PUL=33, DIR=40, ENA=22, BOARD
numbering). It adds trapezoidal ramps, several axes stepped together
(Bresenham), soft limits and endstop homing.

Linux cannot time pulses reliably (expect jitter and a ceiling of a few
kHz), so keep DM542 microstepping low (400-800 pulses/rev) and use this only
on the bench. The robot uses the Klipper backend.
"""
from __future__ import annotations

import time
from dataclasses import dataclass
from typing import Dict, Iterable, Optional

from ..config import RobotConfig
from .base import MotionBackend, MotionError


@dataclass(frozen=True)
class Pins:
    pul: int
    dir: int
    ena: Optional[int] = None
    endstop: Optional[int] = None
    invert_dir: bool = False
    ena_active_low: bool = True  # DM542: ENA+ high = motor free


# The current bench rig: one DM542 on the lift axis.
BENCH_PINS = {"lift_left": Pins(pul=33, dir=40, ena=22)}


class JetsonGPIOBackend(MotionBackend):
    def __init__(self, pins: Dict[str, Pins] = BENCH_PINS, config: Optional[RobotConfig] = None, pulses_per_rev: int = 400):
        import Jetson.GPIO as GPIO  # only on the Jetson

        self.GPIO = GPIO
        self.cfg = config or RobotConfig()
        self.axes = self.cfg.axes
        self.pins = pins
        self.ppr = pulses_per_rev
        self._pos: Dict[str, float] = {a: self.axes[a].home_pos for a in pins}
        GPIO.setmode(GPIO.BOARD)
        for p in pins.values():
            GPIO.setup(p.pul, GPIO.OUT, initial=GPIO.LOW)
            GPIO.setup(p.dir, GPIO.OUT, initial=GPIO.LOW)
            if p.ena is not None:
                GPIO.setup(p.ena, GPIO.OUT, initial=GPIO.LOW if p.ena_active_low else GPIO.HIGH)
            if p.endstop is not None:
                GPIO.setup(p.endstop, GPIO.IN)

    def steps_per_mm(self, axis: str) -> float:
        return self.ppr / self.axes[axis].rotation_distance

    # ----- motion -------------------------------------------------------
    def move(self, targets: Dict[str, float], speed: float, accel: Optional[float] = None) -> None:
        for a, pos in targets.items():
            if a not in self.pins:
                raise MotionError(f"{a} is not wired on the bench rig")
            ax = self.axes[a]
            if not ax.min_pos <= pos <= ax.max_pos:
                raise MotionError(f"{a}={pos:.1f} outside [{ax.min_pos}, {ax.max_pos}]")
        steps = {a: round((targets[a] - self._pos[a]) * self.steps_per_mm(a)) for a in targets}
        lead = max(steps, key=lambda a: abs(steps[a]), default=None)
        if lead is None or steps[lead] == 0:
            return
        v = min(speed, min(self.axes[a].max_speed for a in targets))
        acc = accel or min(self.axes[a].accel for a in targets)
        self._run(steps, lead, v * self.steps_per_mm(lead), acc * self.steps_per_mm(lead))
        for a in targets:
            self._pos[a] += steps[a] / self.steps_per_mm(a)

    def _run(self, steps: Dict[str, int], lead: str, v_max: float, a_max: float, stop_pin: Optional[int] = None) -> int:
        """Step all axes; `lead` sets the timing, others follow by Bresenham.
        Trapezoidal profile in steps/s. Returns steps done on the lead axis."""
        G = self.GPIO
        for a, n in steps.items():
            p = self.pins[a]
            G.output(p.dir, G.HIGH if (n > 0) != p.invert_dir else G.LOW)
        time.sleep(10e-6)  # DM542 direction setup time
        n = abs(steps[lead])
        err = {a: n // 2 for a in steps}
        ramp = int(v_max * v_max / (2 * a_max))
        t = time.perf_counter()
        for i in range(n):
            if stop_pin is not None and G.input(stop_pin):
                return i
            to_go = n - i
            v = min(v_max, (2 * a_max * (i + 1)) ** 0.5, (2 * a_max * to_go) ** 0.5) if ramp else v_max
            period = 1.0 / max(v, 50.0)
            for a in steps:
                err[a] -= abs(steps[a])
                if err[a] < 0:
                    err[a] += n
                    G.output(self.pins[a].pul, G.HIGH)
            t_high = time.perf_counter() + 5e-6
            while time.perf_counter() < t_high:
                pass
            for a in steps:
                G.output(self.pins[a].pul, G.LOW)
            t += period
            while time.perf_counter() < t:  # busy-wait: sleep() is far too coarse
                pass
        return n
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

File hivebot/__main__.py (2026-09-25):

"""Command line.

  python3 -m hivebot plan --box 1            dry run on the simulator, prints every move
  python3 -m hivebot inspect --box 1         real run through Klipper/Moonraker
  python3 -m hivebot home
  python3 -m hivebot bench-move lift_left 700   one axis on the Jetson-GPIO bench rig
"""
from __future__ import annotations

import argparse
import logging
import sys

from .config import RobotConfig
from .motion.base import ALL_AXES
from .sequences import Inspector


def main(argv=None) -> int:
    ap = argparse.ArgumentParser(prog="hivebot")
    sub = ap.add_subparsers(dest="cmd", required=True)
    plan = sub.add_parser("plan", help="simulate an inspection and print the moves")
    plan.add_argument("--box", type=int, default=1)
    plan.add_argument("--quiet", action="store_true")
    ins = sub.add_parser("inspect", help="inspect one box on the real robot")
    ins.add_argument("--box", type=int, default=1)
    ins.add_argument("--moonraker", default="http://127.0.0.1:7125")
    home = sub.add_parser("home")
    home.add_argument("--moonraker", default="http://127.0.0.1:7125")
    bench = sub.add_parser("bench-move", help="move one axis on the Jetson-GPIO bench rig")
    bench.add_argument("axis", choices=ALL_AXES)
    bench.add_argument("position", type=float)
    bench.add_argument("--speed", type=float, default=10.0)
    args = ap.parse_args(argv)
    logging.basicConfig(level=logging.INFO, format="%(message)s")
    cfg = RobotConfig()

    if args.cmd == "plan":
        from .motion.sim import SimBackend

        sim = SimBackend(cfg)
        insp = Inspector(sim, cfg)
        insp.home()
        t0 = sim.clock
        report = insp.inspect(args.box)
        if not args.quiet:
            for entry in sim.log:
                print(*entry)
        print(f"\nbox {args.box}: {len(report.frames)} frames, stack above weighs {report.lifted_kg:.1f} kg, "
              f"visit takes {(sim.clock - t0) / 60:.1f} min (simulated)")
        for w in report.warnings:
            print("warning:", w)
        return 0

    if args.cmd in ("inspect", "home"):
        from .motion.klipper import KlipperBackend

        backend = KlipperBackend(args.moonraker, cfg)
        insp = Inspector(backend, cfg)
        insp.home()
        if args.cmd == "inspect":
            report = insp.inspect(args.box)
            print(f"box {args.box}: {len(report.frames)} frames captured")
        return 0

    if args.cmd == "bench-move":
        from .motion.jetson_gpio import JetsonGPIOBackend

        backend = JetsonGPIOBackend(config=cfg)
        try:
            backend.move({args.axis: args.position}, args.speed)
        finally:
            backend.close()
        return 0
    return 1


if __name__ == "__main__":
    sys.exit(main())

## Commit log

2024-06-14 Add files via upload
    Uploaded All test + Original Files for Development Phase.
    [30mm bearing.FCStd, 40x60x50-Plate.FCStd, Aluminium Extrusion.FCStd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]
2024-06-17 Updated Static Assembly with some components
    [Aluminium-Bar.FCStd, Butterfly-Static.FCStd, CADLatest.FCStd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]
2024-06-17 add servo motor controller
2024-06-17 move cad model files into folders, add more readme
    [30mm bearing.FCStd, 40x60x50-Plate.FCStd, Aluminium Extrusion.FCStd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]
2024-06-27 Multi-Storey-Beehive-CAD
    Added pdf + cad files for Multistorey beehive robot
2024-06-27 Beehive Box Closed Assembly File
    [beehibe-box-closed-asm.FCStd]
2025-03-16 revert to pin-based pulse
    [main.py]
2026-09-25 feat: add Hive Tower control stack, design docs, and 3D pipeline
    - Add hivebot package with inspection sequences, safety policy, capture hooks, and motion backends (physics sim, Klipper/Moonraker, Jetson GPIO bench) plus CLI plan/inspect/home/bench-move
    - Add firmware/klipper/hivebot.cfg for BTT Octopus manual_steppers, servos, heaters, and interlocks aligned with hivebot/config.py geometry
    - Add DESIGN.md, WIRING.md, wiring.svg, and wiring_diagram.py for concept v3 and r...
    [hivebot.cfg]
2026-09-25 feat(inspection): fixed photo spot for frames and file:// 3D viewer
    - Centre each lifted frame at geometry.photo_z via a shuttle move before capture so dual-face shots share distance, focus, and scale
    - Model pin pocket_depth in the motion sim and tighten hook pull-back rules; nudge lift/scan axis minimums in config
    - Add build-viewer.mjs to emit self-contained model/index.html from the template plus inlined hive-model.js; wire it into npm build
    - Align DESIGN, README, vi...
    [config.py, sequences.py, sim.py]
2026-09-25 feat(viewer): bundle 3D viewer for website embed, remove old CAD models
    - Split the viewer into viewer.js (mountHiveTower), viewer.html and
    viewer.css, bundled with three.js by esbuild. index.html is now a single
    self-contained file that works offline.
    - `npm run website` copies the bundle, CSS and GLB into gratheon.com and
    refreshes the embed on the robotic beehive product page.
    - Remove the FreeCAD models of earlier concepts (CAD-model/); they remain
    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
    [30mm bearing.FCStd, 40x60x50-Plate.FCStd, Aluminium Extrusion.FCStd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]
2026-09-25 Rename Hive Tower to Robotic Beehive in docs and viewer.
    Align product naming across the open-source model, wiring docs, and embedded viewer strings.
    [hivebot.cfg]
2026-09-25 Use PCFShadowMap and Timer in the hive tower viewer.
    Removes Three.js r186 deprecation warnings in the embedded product viewer.
2026-10-03 feat: support mixed deep/super stacks with two frame cameras
    - Replace the fixed box count with a bottom-to-top stack of named body
    types (deep 285/279 mm, super 170/164 mm) across config, geometry,
    the three.js model, the GLB exporter and the viewer selectors, so
    per-box heights and frame heights are looked up instead of assumed.
    - Cut the four half-face cameras down to two CSI cameras on the lift
    beams, one per face, and derive frame lift from the comb centre so
    deep and shallow frames both arrive level with the camera axis;
    tests now assert a near-zero camera offset for every box.
    - Vendor the Entrance Observer porch model (with a sync-observer
    script), rewire its power as a 24→48 V PoE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
    [config.py, hive-model.js, sequences.py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]
2026-10-25 ci: add Ruff and ty checks, fix broken files
    gripper-servo-motor-control.py did not parse (a stray 'chrome+' was pasted
    into it), and stop_program() in main.py set a local motor_running instead of
    the global flag. ty is pinned to 0.0.91 because it is beta; sim backend now
    narrows optional box and frame indexes explicitly.
    Claude-Session: https://claude.ai/code/session_01FnCxhjs27NSecN5DwQ9dai
